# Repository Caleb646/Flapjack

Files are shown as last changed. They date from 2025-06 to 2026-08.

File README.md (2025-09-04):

# 🥞 Flapjack

Flapjack is a **VTOL drone platform** built from the ground up — custom **airframe**, **PCB**, and **firmware**.
---

## Features

- **Custom Flight Controller PCB**
    - STM32 microcontroller
    - IMU (SPI), barometer, GPS, and compass
    - Servo and ESC outputs

- **Firmware**
    - Python GUI for flight data
    - Real-time flight control loop
    - Sensor fusion (IMU + barometer + compass)
    - PID control
    - PID Mixing for tilt-thrust VTOL (motor + servo)

- **Airframe**
    - Dual-motor VTOL design with tilt servos
    - Lightweight and modular construction
    - Designed for hover-to-cruise transitions

---

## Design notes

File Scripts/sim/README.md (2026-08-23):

# Flapjack JSBSim HIL Simulator

Hardware-in-the-loop sim for the tilt-rotor. The firmware runs on the real
STM32H745 **or on an emulated CM7 under Renode** (see [SIL mode](#sil-mode-no-board-required)
below); this PC tool runs **JSBSim** and exchanges data with it over the (now
binary) debug UART:

```
 PC: JSBSim + bridge.py  ◄──ServoCmd/MotorCmd────  FC (sim driver profile)
                         ◄──Telemetry────────────  (validation + sensor loopback)

                         ──CRSF 0x16────────────►  FC RX UART  (USART3)
                         ──NMEA GGA/RMC─────────►  FC GPS UART (USART2)

                         ──accel, gyro──────────►  emulated BMI323  (tcp 4010) ─► SPI1
                         ──field────────────────►  emulated MMC5983 (tcp 4011) ─┐
                         ──Pa, degC─────────────►  emulated BMP390  (tcp 4012) ─┴► SPI5
```

**Nothing reaches the FC pre-decoded.** RC and GPS go down separate wires as real
CRSF and real NMEA, exactly as the parts would drive them, so a SIL run exercises
the UART ISRs, the deframing, the checksums and the parsers. There used to be an
`RcInput` sim-link message that wrote `g_Rx.channels` directly; it bypassed all
of that and has been removed.

The three **sensors** follow the same principle one level down. A register read
is not a byte protocol, but it is still a path with a chip select, a dummy byte,
an address auto-increment and a data-ready bit to get wrong — so rather than
inject decoded values at the driver, the bridge pushes physical quantities into
emulated parts and the firmware reads them back through its real `bmi323`,
`mmc5983` and `bmp390` drivers over emulated SPI. That put five firmware defects
on the record for the IMU alone (KnownIssues §2.29–§2.33), and for the baro it
puts the 21-byte calibration decode and the compensation polynomial on the
critical path.

**Frame ids 1 (`SensorData`), 2 (`RcInput`) and 7 (`BaroData`) are retired — do
not reuse them.** The sim link is FC→PC only now, apart from the shell.

- **PC → FC:** IMU (accel m/s², gyro deg/s) and mag (**gauss**) pushed at 400 Hz,
  baro (Pa, °C) at 50 Hz, each into its own emulated part; RC channels as CRSF
  `0x16` frames on the RX UART; GPS as NMEA `GGA`/`RMC` on the GPS UART.
- **FC → PC:** per-servo tilt **angle** (rad) and per-motor **throttle** (0–1),
  plus a `Telemetry` frame (nav euler, armed, IMU sample count, RC link state,
  and the baro/GPS **loopback** described below).

Mag is pushed in gauss, not as a unit vector, because the MMC5983 has a real
±8 G full scale that `mmc5983.c` divides by — a unit vector would assert that
Earth's field saturates the part. Nothing downstream depends on the magnitude
(Madgwick renormalises), but the scale is now a testable property rather than an
assumption.

### The sensor loopback

`Telemetry` echoes back the baro pressure and GPS fix the firmware decoded, read
from the **umsg topics** rather than from the sim link's own decode slots. The
bridge asserts every echo matches something it actually sent:

- **baro: bit-exact.** Both hops are IEEE 754 binary32, so a correct chain
  reproduces the sent value exactly — no tolerance, and under `--dry-run` the
  pressure is *swept* so a latched or stale value cannot pass by accident.
- **GPS: within ~1.1 cm.** NMEA quantises the coordinate to 5 decimal places of a
  minute (~1.9 cm), so the check compares against the post-quantisation value.
  The tolerance is tight enough that narrowing the chain back to `float`
  (~2.2e-6 deg at mid latitudes) fails.

This covers the whole chain — wire, driver, device, umsg publish — in one
comparison. It is specifically the check that catches a parser which succeeds
while discarding its result, which is exactly what `Gps_Update_` used to do.

Timing is **free-running real-time**: sensors stream at a fixed rate and JSBSim
is stepped to wall-clock; the FC consumes the latest sample and replies async.

## 1. Install

From the repo root (installs JSBSim + the shared base deps):

```
pip install -e ".[sim]"
```

The Python proto stub lives at `Scripts/proto/sim_pb2.py` and is regenerated
(alongside the firmware's nanopb `Firmware/msgs/proto/sim.pb.{c,h}`) by:

```
python Scripts/board.py gen
```

(`build -b flapjack-v1 -D sim -f g` regenerates the same as part of a full build.)
`sim.proto` is the **single source of truth** for both.

## 2. Build + flash the HIL firmware

Configure the firmware with the `sim` driver profile (selects the sim backends
for imu/mag/baro/servo/motor and defines `SIM_HIL`):

```
python Scripts/board.py build -b flapjack-v1 -D sim
```

In this build the shared UART (UART_1, `SERIAL_LINK_BAUD_RATE` = 460800) carries binary sim
frames **and** ASCII debug logs, interleaved; the shell shares it too, as frame id
6. `bridge.py` separates them and prints the log text to stdout. Log output is
7-bit ASCII and the frame magic is `0xAA`, which is what makes the two
unambiguous — see `Firmware/drivers/serial/serial_link.h`.

Wire the board's UART_1 TX/RX to a USB-serial adapter on the PC. On real hardware
the receiver drives UART_3 (`RX_UART`, 416666 baud 8N1) as usual — the bridge's
`--rc-port` stands in for it only under Renode.

## 3. Bring up the link FIRST (no FDM needed)

`--dry-run` skips JSBSim and emits a fixed **20° roll** attitude. This validates
the serial link, the FC's sensor decode/frames, and the telemetry echo without
any flight model:

```
python Scripts/board.py sim --port COM7 --dry-run
```

Expected: the `[FC] euler(deg)=` line should converge to roll ≈ **+20°**,
`armed=True` shortly after start, and `imu#` increasing (proves the IMU task is
paced by the incoming stream). If euler roll is negative or on the wrong axis,
flip the sign in `synthesize_sensors()` (clearly marked).

## 4. Run the full sim

```
python Scripts/board.py sim --port COM7
```

The bridge loads `Scripts/sim/jsbsim/aircraft/tiltrotor/tiltrotor.xml`, raises the
arm switch after `--arm-delay`, waits for the FC to report armed, then goes to
hover throttle, applies the FC's servo/motor commands to the model, and streams
synthesized sensors back.

**Every wire defaults to its SIL socket**, so a SIL run is just `board.py sim` with no flags.
The defaults apply only while `--port` is a socket, i.e. while this is a SIL run — naming a real
device turns them all off, because on a board the companion wires are physical ports nobody can
guess. Pass `none` to any one of them (`--gps-port none`) to leave that wire off, which is how
the "no receiver" and "no fix" paths stay testable. Useful flags:

| flag | default | meaning |
|---|---|---|
| `--port` | `socket://localhost:4000` | the FC's sim link. The default is a SIL run; give a real device (`COM7`, `/dev/ttyUSB0`) to drive a board |
| `--baud` | 460800 | must match the board's `SERIAL_LINK_BAUD_RATE` |
| `--rate` | 400 | sensor stream rate (Hz) |
| `--model` | tiltrotor | JSBSim aircraft name under `--root/aircraft/` |
| `--hover-throttle` | 0.5 | throttle held once armed, when no `--plan` is given |
| `--rc-port` | `socket://localhost:4001` | port carrying CRSF to the FC's RX UART. **The only RC path** — with `none` the FC never arms |
| `--rc-baud` | 416666 | CRSF spec default; ignored for a `socket://` URL |
| `--rc-rate` | 50 | CRSF frame rate (Hz); a real link runs 50–150 |
| `--imu-port` | `socket://localhost:4010` | socket carrying accel/gyro to the emulated BMI323. **The only IMU path** — with `none` there is no attitude |
| `--mag-port` | `socket://localhost:4011` | socket carrying the field in gauss to the emulated MMC5983. **The only mag path** |
| `--mag-rate` | 100 | magnetometer push rate (Hz). The emulated part raises drdy on every push, so this **is** the FC's mag interrupt rate — it matches the 100 Hz `mmc5983.c` programs, and pushing faster models a part the board does not have |
| `--baro-port` | `socket://localhost:4012` | socket carrying Pa/°C to the emulated BMP390. **The only baro path** |
| `--baro-rate` | 50 | barometer push rate (Hz), matching the ODR `bmp390.c` programs; also the FC's baro interrupt rate. 0 disables baro |
| `--gps-port` | `socket://localhost:4002` | port carrying NMEA to the FC's GPS UART. **The only GPS path** |
| `--gps-baud` | 115200 | matches `GPS_BAUD_RATE`; ignored for a `socket://` URL |
| `--gps-rate` | 10 | fix rate (Hz). GGA and RMC go out half a period apart — the driver holds one sentence, so a burst would lose the first |
| `--plan` | (none) | YAML flight plan to fly once armed |
| `--rc-stop` | (none) | stop sending CRSF after N seconds, imitating a receiver failsafe |
| `--hold-until-armed` | on | freeze the FDM at its IC until the FC arms |

### Flight plans

`--plan Scripts/sim/plans/hover.yaml` replays a scripted stick sequence instead
of the fixed arm-and-hover gesture. A plan is a list of timed segments that `set`
or `ramp` named channels in microseconds:

```yaml
name: yaw_step
plan:
  - {t: 0.0,  dur: 3.0}
  - {t: 3.0,  dur: 2.0, ramp: {throttle: 1500}}
  - {t: 8.0,  dur: 2.0, set:  {yaw: 1700}}
  - {t: 10.0, dur: 3.0, set:  {yaw: 1500}}
```

Two properties make runs comparable. **Arming is a barrier, not a timestamp** —
the plan clock starts when the FC reports armed, because the attitude-settle gate
takes a variable amount of time (measured anywhere from 3 s to ~24 s). And **`t`
is simulation time**: the FDM advances exactly one `dt` per tick, so `tick * dt`
is exact, where wall-clock pacing would move the sticks around under host load.

When the plan ends the bridge prints a check summary and exits **0 (pass) or
1 (fail)**. The checks are physics invariants — no NaN, motors inside [0,1] and
not pinned at 1.000, servos inside ±π/2, FC actually armed — which hold of any
correct flight whatever the plan. Per-plan criteria live in the plan itself; see
**Phase-gated plans** below.

> §1.13 records that the attitude a run settles at is not repeatable and is a
> weak regression signal. That was a property of the **rate** loop it was
> measured on: centred sticks commanded zero rate, so the vehicle kept whatever
> bank the transient left. `guidance.c` holds an **angle** now — centred means
> level — so there is a commanded reference to track, which is what phase gates
> compare against.

The **sensor loopback** lines are the exception: they *are* exact assertions, and
they can be, because they compare the firmware against what the bridge itself
sent rather than against an unvalidated flight model. A healthy run reads:

```
[checks] baro         2342 sent, 2331 echoed, 0 mismatched
[checks] gps          976 sent, 976 echoed, 0 mismatched
```

Both lines are silent when the sensor was not streamed, so an older plan or a
`--baro-rate 0` run still passes. `0 echoed` against a non-zero `sent` is a
failure, not a skip — that is the "FC decoded none" case.

### Phase-gated plans

A plain `plan:` is stick input: it flies, but the only thing asserted afterwards
is that the vehicle did not depart or go NaN. A **`phases:`** plan carries its
own PASS/FAIL criteria, and is what `acceptance.yaml` — the regression run — is
built from:

```yaml
name: acceptance
phases:
  - name: climb_in_roll_right
    set:    {roll: 1700, throttle: 1800}   # +12 deg of bank, +0.6 m/s climb
    settle: 4.0                            # transient — NOT gated
    hold:   12.0                           # gates checked on EVERY tick here
    gates:
      roll_deg:     {target: cmd, tol: 2.0}
      climb_mps:    {target: cmd, tol: 0.20}
      pitch_deg:    {target: 0.0, tol: 3.0}   # uncommanded → coupling gate
      yaw_rate_dps: {target: 0.0, tol: 8.0}
```

`set`/`ramp` are applied over `settle`, then the sticks are held still for
`hold`. Splitting them is the point: *did it get there* and *did it stay there*
are different questions, and only the second is a stability check.

**Gate targets.** `target: cmd` compares against what the sticks were asking
for, derived from the plan by `plan.commanded()` — roll and pitch are **angle**
commands (`(µs-1500)/500 × CFG_ANGLE_MAX_DEG`), yaw is a **rate**, throttle is a
**climb rate**. `target: <number>` compares against a constant, which is how an
axis nobody commanded gets asserted — and that is the cross-coupling check: a
roll input that drags pitch with it fails `pitch_deg` even while tracking roll
perfectly.

| gate | measured | kind |
|---|---|---|
| `roll_deg`, `pitch_deg` | FDM truth euler | per-sample |
| `yaw_rate_dps` | FDM truth body rate | per-sample |
| `climb_mps` | FDM `h-dot` | per-sample |
| `alt_drift_m` | altitude change across the hold | per-phase |
| `heading_drift_dps` | heading change ÷ hold length | per-phase |

The drift gates are the reason a long phase is worth flying: `acceptance.yaml`'s
`long_trim_hold` is 150 s of centred sticks, and nothing a 20 s plan does can
express what it asserts.

**The reference comes from the plan, not from the FC.** Comparing the firmware's
own setpoint echo against its own estimate would pass a vehicle that is
confidently wrong — the same argument `KnownIssues.md` §1.16 makes for gating on
FDM truth rather than on `Telemetry.euler`.

**Failures are loud and early.** The first violation prints the instant it
happens with its phase, plan time, expected and measured values, and the run
**stops** — so the failure is the last thing on the terminal instead of buried
under the remaining minutes of log. `--keep-going` surveys the rest instead.
Everything gate-related is prefixed `[gate]`, so `grep '^\[gate\]'` is the whole
report; logs, telemetry and the shell all share USART1, which is what makes that
matter. A machine-readable copy lands in `Build/sil_report.json`
(`--gate-report`), for diffing one build against another.

```
[gate] ------------------------------------------------------------
[gate] phase                 gate               worst   limit      n
[gate] climb_in_roll_right   roll_deg           0.812   2.000    4800  PASS
[gate] climb_in_roll_right   pitch_deg          3.441   3.000    4800  FAIL
[gate] not reached: level_1, climb_in_roll_left, ...
[gate] FIRST FAILURE  climb_in_roll_right/pitch_deg at plan t=63.20s
[gate]   expected +0.000, measured -3.441, error 3.441 > tol 3.000
[gate] FAIL (1 failed, 22 never ran)
```

**A gate that never ran fails.** A phase shorter than a tick, or one the run
aborted before reaching, reports `NOT RUN` and counts against the verdict — a
green line for a criterion nobody evaluated is exactly how a regression suite
stops meaning anything. Gate and channel names are validated at load, so a typo
is an error rather than a gate that silently never fires.

**Tolerances must be measured, not guessed.** `acceptance.yaml`'s are starting
values and are marked as such. Fly it several times on a known-good build, take
the worst error each gate actually reaches, set the limit near 3× that, and
record the spread in a comment — the treatment `ATTITUDE_SETTLE_PKPK_DEG` in
`bridge.py` already documents. A flaky gate is worse than no gate.

## Wire protocol

`[0xAA][0x55][msg_id][len][payload][crc8]` — `crc8` poly 0x07, init 0x00, over
`(msg_id,len,payload)`; payload is protobuf (`sim.proto`). Defined identically in
`Firmware/drivers/sim_link/sim_link.c` and the shared host framing
`Scripts/link/framing.py` (used by the bridge).

## Status / caveats

- **The CRSF path is unit-tested on the host.** `Tests/UnitTest/test_crsf.c` checks
  the firmware's deframer, CRC, channel unpack and tick→µs mapping against the spec,
  and asserts a golden frame produced by `Scripts/sim/crsf.py` byte for byte, so the
  encoder here and the decoder there cannot drift apart.
- **The NMEA path is too.** `Tests/UnitTest/test_gps.c` does the same job for GPS
  against golden sentences from `Scripts/sim/nmea.py`: the byte assembler
  (resync, partial sentences, one-byte-at-a-time delivery), the coordinate and
  knots→m/s conversions, checksum rejection, and that a void RMC or a
  `fix_quality` 0 GGA is **not** reported as a fix.
- **The sensor models come from JSBSim.** `SensorBaro.xml` and `SensorGps.xml` are
  vendored into `jsbsim/systems/` from the JSBSim distribution and included by
  `tiltrotor.xml`. Their `<noise>`/`<bias>`/`<drift_rate>` terms are **on** — see
  `KnownIssues.md` §3.13 for each value and why. Tune realism **there**, not in
  `bridge.py`. There is still **no IMU noise model**: the gyro and accel the
  bridge synthesises are exact. `SensorImu.xml` is deliberately **not** used —
  its accelerometer reports the opposite Z sign to this project's convention, and
  its magnetometer disagrees with WMM in both sign and magnitude (32.2 µT against
  ~48 µT real).
- **The FDM is sized to the real airframe** (0.85 kg, 7 in props, 1000 KV assumed
  on 6S): hover at 50 % throttle, 2:1 thrust-to-weight, tilt verified against
  measured force directions. Thrust comes from `<external_reactions>` rather than
  JSBSim's propeller model, which diverged — see `SilResearch.md` §6.
  Inertias are still estimates, and `ROTOR_TMAX` (1.874 lbf per rotor) is the one
  number to replace with thrust-stand data.
- **Forward flight is approximated** by a thrust-vs-airspeed table rather than
  blade-element physics. Fine for hover and low-speed control work; revisit before
  trusting cruise or transition results.
- **The gains are provisional.** The stack flies closed-loop, but the tune is
  fitted to an estimated rotor height and unmeasured servo dynamics — see
  `KnownIssues.md` §1.9. `roll_pitch.yaml` still departs (§1.14); `hover`,
  `yaw_step` and `alt_hold` pass.

---

## SIL mode (no board required)

Renode emulates the CM7 and exposes **both** UARTs as TCP servers, so the bridge
talks to sockets instead of COM ports — USART1 (sim link) on 4000 and USART3
(the RX UART, carrying CRSF) on 4001. Nothing else changes: same framing, same
protobuf messages, same `bridge.py`.

```bash
python Scripts/board.py build -b flapjack-v1 -D sim --single-core
python Scripts/board.py renode -b flapjack-v1                          # terminal 1
python Scripts/board.py sim                                            # terminal 2
```

USART2 (the GPS UART) is exposed on **4002** alongside the other two. Like
USART3 it needed no Renode work beyond a frequency pin — it is a real
`UART.STM32F7_USART` in the shipped platform. `--gps-port` is optional: leave it
off and `Gps_Task` simply never sees a fix, and the GPS checks stay silent.

`renode` takes the place of `flash`; it blocks until Ctrl-C. **Restart it between
runs** rather than re-attaching the bridge: a gap in the sensor stream hands
`Nav_Update` one enormous `dt`, which throws the attitude estimate and costs
several seconds of recovery.

Measured behaviour (see `SilResearch.md` §3):

- Renode tracks wall clock **1.00x** under load, so the bridge's real-time pacing
  is correct as-is.
- **400 Hz sustains with 0.0 % dropped `SensorData`**; the ceiling is ~740/s,
  beyond which throughput collapses.
- `Telemetry.imu_count` vs frames sent is the health metric — it should track 1:1.

The FC arms itself: `bridge.py` holds throttle low with the switch up after
`--arm-delay` (2.0 s) and waits for `Telemetry.armed`. The interlock that decides
when is in the firmware, not the bridge — the estimate must be converged and
still for 3 s (`KnownIssues.md` §2.13) — so arming lands anywhere from ~3 s to
~24 s in. Ground start and landing are fine; the gear no longer diverges (§3.4).

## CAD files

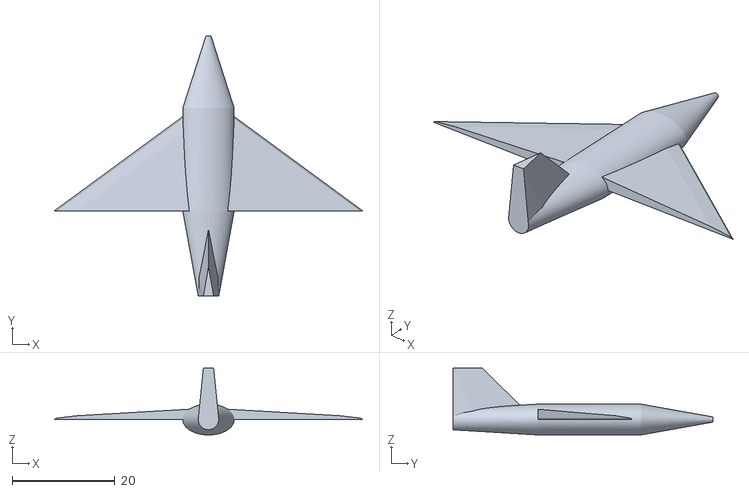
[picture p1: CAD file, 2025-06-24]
Scripts/gui/data/mesh/plane.stl
60.0 x 50.5 x 13.0

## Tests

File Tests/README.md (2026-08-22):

# Flapjack tests

Two independent suites that share nothing but the vendored Unity in `Tests/unity/`.

| | `Tests/UnitTest/` | `Tests/HIL/` |
|---|---|---|
| Runs on | the host (x86) | the board |
| Built by | `Tests/CMakeLists.txt` (standalone CMake project) | the firmware build, `board.py build -f t` |
| Purpose | pure logic against controlled inputs | drivers against real peripherals |

---

## Host unit tests

```bash
cmake -S Tests -B Build/UnitTest -G "MinGW Makefiles"   # "Unix Makefiles" on Linux
cmake --build Build/UnitTest
ctest --test-dir Build/UnitTest --output-on-failure
```

No toolchain and no network needed — this compiles firmware sources with the host compiler
against `UnitTest/stubs/hal_stub.c`, and Unity is vendored rather than fetched.

### Current contents

Four suites. Two of them assert a **golden frame** produced by the host encoder the SIL uses, so
the encoder there and the decoder here cannot drift apart.

- **`test_crsf.c`** — the receiver path in `drivers/rx/crsf.c` against the TBS CRSF specification:
  frame layout and the 2–62 length range, CRC8 (poly 0xD5, over type + payload), the
  16 × 11-bit LSB-first channel unpack, the `TICKS_TO_US` mapping, and the spec's rule that a
  longer-than-expected frame must be accepted with its extra fields ignored. Golden frame from
  `Scripts/sim/crsf.py`.
- **`test_gps.c`** — the NMEA path: the byte assembler (resync, partial sentences,
  one-byte-at-a-time delivery), the coordinate and knots→m/s conversions, checksum rejection, and
  that a void RMC or a `fix_quality` 0 GGA is **not** reported as a fix. Golden sentences from
  `Scripts/sim/nmea.py`.
- **`test_altitude.c`** — the ISA pressure conversion against an **analytic oracle** (SilResearch
  §5.2), plus the vertical complementary filter: convergence to the measurement, acceleration
  integration in between, and bias absorption.
- **`test_align.c`** — the board/sensor alignment composition.

### Adding a test

Add the source under `UnitTest/`, then in `Tests/CMakeLists.txt` put its firmware dependencies in
an `add_library(... OBJECT ...)` and register it:

```cmake
add_test_exe(test_thing OBJECTS drone_common_obj drone_thing_obj)
```

Two constraints worth knowing before you pick what to compile in:

- **`spi.c` and `uart.c` do not build against the stub.** `stubs/hal_stub.c` has no `LL_SPI_*` and
  none of the `__HAL_UART_*` macros. Either extend the stub, or do what `test_crsf.c` does and
  define the two or three functions your unit actually needs directly in the test file.
- **MinGW needs `-mno-ms-bitfields`** (the build sets it globally). Under MSVC bitfield layout
  `CrsfChannelsPayload_t` packs to 32 bytes instead of the 22 ARM EABI produces, and the host would
  silently exercise a wire format the firmware never emits. `test_crsf.c` carries a
  `_Static_assert` on that size; do the same for any other struct whose memory layout is the thing
  under test.

Note that `GetMicroseconds()` returns **0** under `UNIT_TEST` (`core/core_shared.c`), so anything
gated on elapsed time — the CRSF inter-frame timeout, the RC link timeout — cannot be reached from
here. Those need a time seam that does not exist yet.

### History

This suite previously held tests for queue, vector, umap, gpio, spi, uart, imu, mag, dshot and
filter. None of them had built for some time: they all include `"unity/unity.h"`, while
`CMakeLists.txt` fetched Unity to `_deps/unity-src/src/`, where that path cannot resolve — and
several of their dependencies no longer compile against the HAL stub. They were removed rather
than left as decoration. Restoring any of them means fixing the target against the two constraints
above; the sources are in git history.

---

## HIL tests

Firmware compiled with `HIL_TEST=True` runs Unity on the board at boot and streams results over
UART:

```bash
python Scripts/board.py build -b flapjack-v1 -f t
python Scripts/board.py flash -b flapjack-v1 -f t --port <PORT> --baud 230400
```

`flash -f t` parses the stream and exits 0 (all pass) or 1 (failures). Output format:

```
file.c:42:test_name:PASS
file.c:43:test_name:FAIL:Expected X Was Y
N Tests M Failures 0 Ignored
```

---

## The third kind: the SIL

Neither suite covers the GNC loop end to end. That is the SIL's job — Renode plus JSBSim, driven
by `board.py renode` and `board.py sim`. A flight plan run (`sim --plan …`) exits 0 or 1 on a set
of physics invariants, which makes it usable as a coarse regression gate. See `SilResearch.md`
and the `flapjack-sil-debugging` skill.

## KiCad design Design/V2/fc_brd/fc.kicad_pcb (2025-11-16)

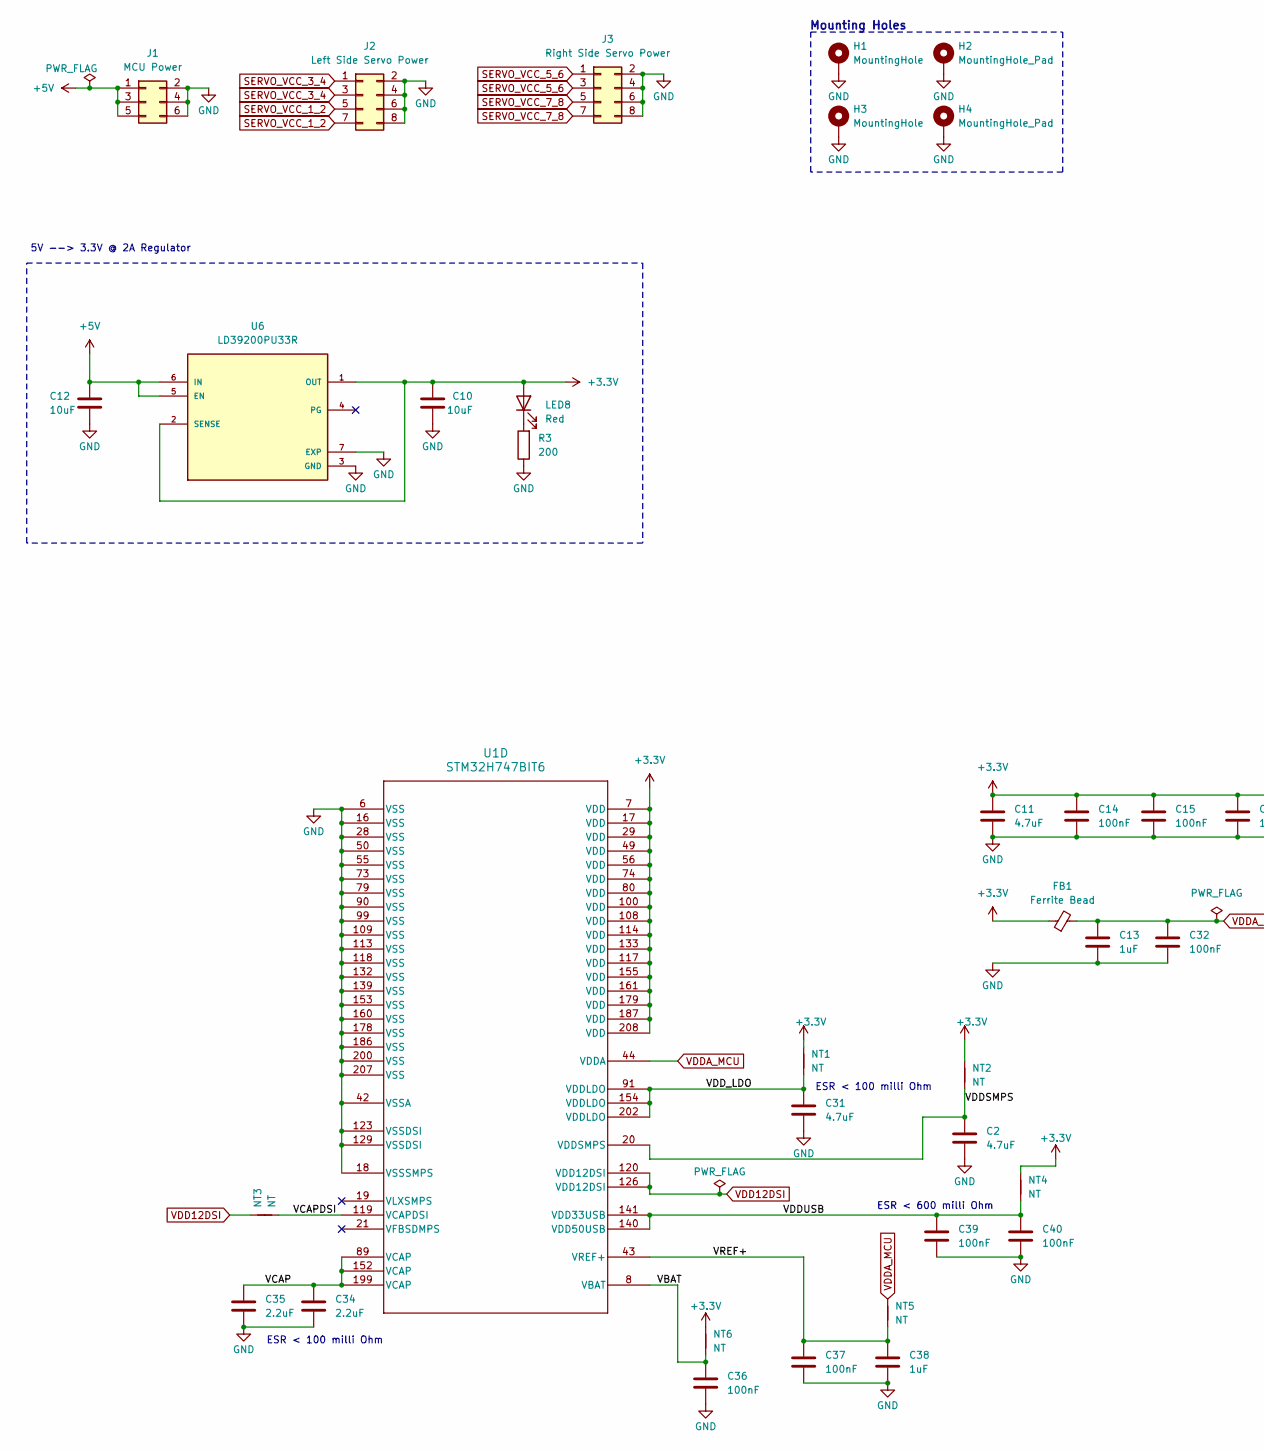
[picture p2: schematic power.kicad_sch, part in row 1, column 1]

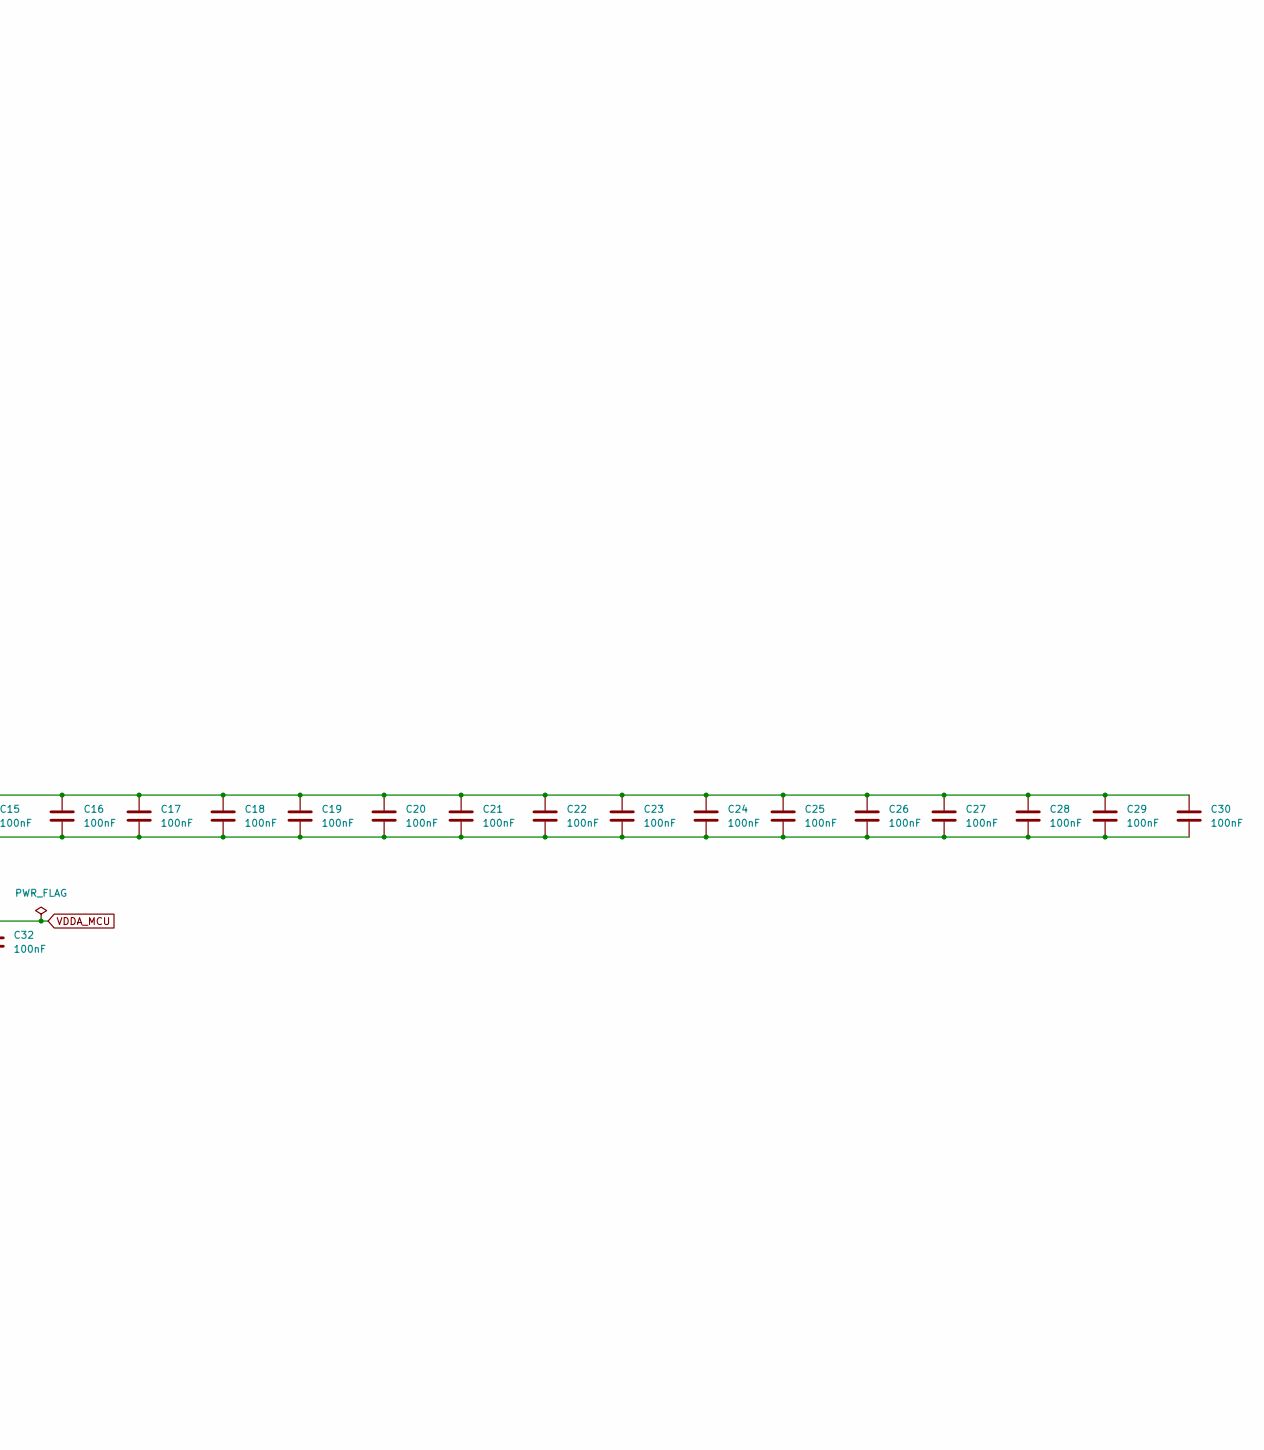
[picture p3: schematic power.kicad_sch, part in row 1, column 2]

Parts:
C2, C11, C31: 4.7uF; C_0603_1608Metric_Pad1.08x0.95mm_HandSolder; Manufacturer_Part_Number CL10A475KO8NNNC; LCSC Part # C19666
C10, C12: 10uF; C_0603_1608Metric_Pad1.08x0.95mm_HandSolder; Manufacturer_Part_Number CL10A106KP8NNNC; LCSC Part # C19702
C13, C38: 1uF; C_0603_1608Metric_Pad1.08x0.95mm_HandSolder; Manufacturer_Part_Number CL10A105KB8NNNC; LCSC Part # C15849
C14, C15, C16, C17, C18, C19, C20, C21, C22, C23, C24, C25, C26, C27, C28, C29, C30, C32, C36, C37, C39, C40: 100nF; C_0603_1608Metric_Pad1.08x0.95mm_HandSolder; Manufacturer_Part_Number CC0603KRX7R7BB104; LCSC Part # C14663
C34, C35: 2.2uF; C_0603_1608Metric_Pad1.08x0.95mm_HandSolder; Manufacturer_Part_Number CL10A225KO8NNNC; LCSC Part # C23630
FB1: Ferrite Bead; L_0603_1608Metric_Pad1.05x0.95mm_HandSolder; Manufacturer_Part_Number BLM18PG121SN1D; LCSC Part # C14709
H1, H3: MountingHole; MountingHole_3.2mm_M3_Pad_Via
H2, H4: MountingHole_Pad; MountingHole_3.2mm_M3_Pad_Via
J1: MCU Power; PinHeader_2x03_P2.54mm_Vertical
J2: Left Side Servo Power; PinHeader_2x04_P2.54mm_Vertical
J3: Right Side Servo Power; PinHeader_2x04_P2.54mm_Vertical
LED8: Red; LED_0603_1608Metric; Manufacturer_Part_Number KT-0603R; LCSC Part # C2286
NT1, NT2, NT3, NT4, NT5, NT6: NT; NetTie-2_SMD_Track0.35mm
R3: 200; R_0603_1608Metric_Pad0.98x0.95mm_HandSolder; Manufacturer_Part_Number 0603WAF2000T5E; LCSC Part # C8218
U1: STM32H747BIT6; STM32H747BIT6-LQFP-208; Manufacturer_Part_Number STM32H747BIT6; LCSC Part # C730197
U6: LD39200PU33R; SON95P300X300X100-7N; Manufacturer_Part_Number LD39200PU33R; LCSC Part # C222192

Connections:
/Power/VBAT: C36.1, NT6.2, U1.8 (VBAT)
/Power/VCAP: C34.1, C35.1, U1.89 (VCAP), U1.152 (VCAP), U1.199 (VCAP)
/Power/VCAPDSI: NT3.2, U1.119 (VCAPDSI)
/Power/VDDSMPS: C2.1, NT2.2, U1.20 (VDDSMPS)
/Power/VDDUSB: C39.1, C40.1, NT4.2, U1.140 (VDD50USB), U1.141 (VDD33USB)
/Power/VDD_LDO: C31.1, NT1.2, U1.91 (VDDLDO), U1.154 (VDDLDO), U1.202 (VDDLDO)
/Power/VREF+: C37.1, C38.1, NT5.2, U1.43 (VREF+)
GND: C2.2, C10.2, C11.2, C12.2, C13.2, C14.2, C15.2, C16.2, C17.2, C18.2, C19.2, C20.2, C21.2, C22.2, C23.2, C24.2, C25.2, C26.2, C27.2, C28.2, C29.2, C30.2, C31.2, C32.2, C34.2, C35.2, C36.2, C37.2, C38.2, C39.2, C40.2, H1.1, H2.1, H3.1, H4.1, J1.2, J1.4, J1.6, J2.2, J2.4, J2.6, J2.8, J3.2, J3.4, J3.6, J3.8, R3.1, U1.6 (VSS), U1.16 (VSS), U1.18 (VSSSMPS), U1.28 (VSS), U1.42 (VSSA), U1.50 (VSS), U1.55 (VSS), U1.73 (VSS), U1.79 (VSS), U1.90 (VSS), U1.99 (VSS), U1.109 (VSS), U1.113 (VSS), U1.118 (VSS), U1.123 (VSSDSI), U1.129 (VSSDSI), U1.132 (VSS), U1.139 (VSS), U1.153 (VSS), U1.160 (VSS), U1.178 (VSS), U1.186 (VSS), U1.200 (VSS), U1.207 (VSS), U6.3 (GND), U6.7 (EXP); also elsewhere on the board
unnamed: LED8.1 (K), R3.2
SERVO_VCC_1_2: J2.5, J2.7; also elsewhere on the board
SERVO_VCC_3_4: J2.1, J2.3; also elsewhere on the board
SERVO_VCC_5_6: J3.1, J3.3; also elsewhere on the board
SERVO_VCC_7_8: J3.5, J3.7; also elsewhere on the board
VDD12DSI: NT3.1, U1.120 (VDD12DSI), U1.126 (VDD12DSI)
VDDA_MCU: C13.1, C32.1, FB1.2, NT5.1, U1.44 (VDDA)

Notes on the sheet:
5V --> 3.3V @ 2A Regulator
Mounting Holes
ESR < 100 milli Ohm
ESR < 600 milli Ohm

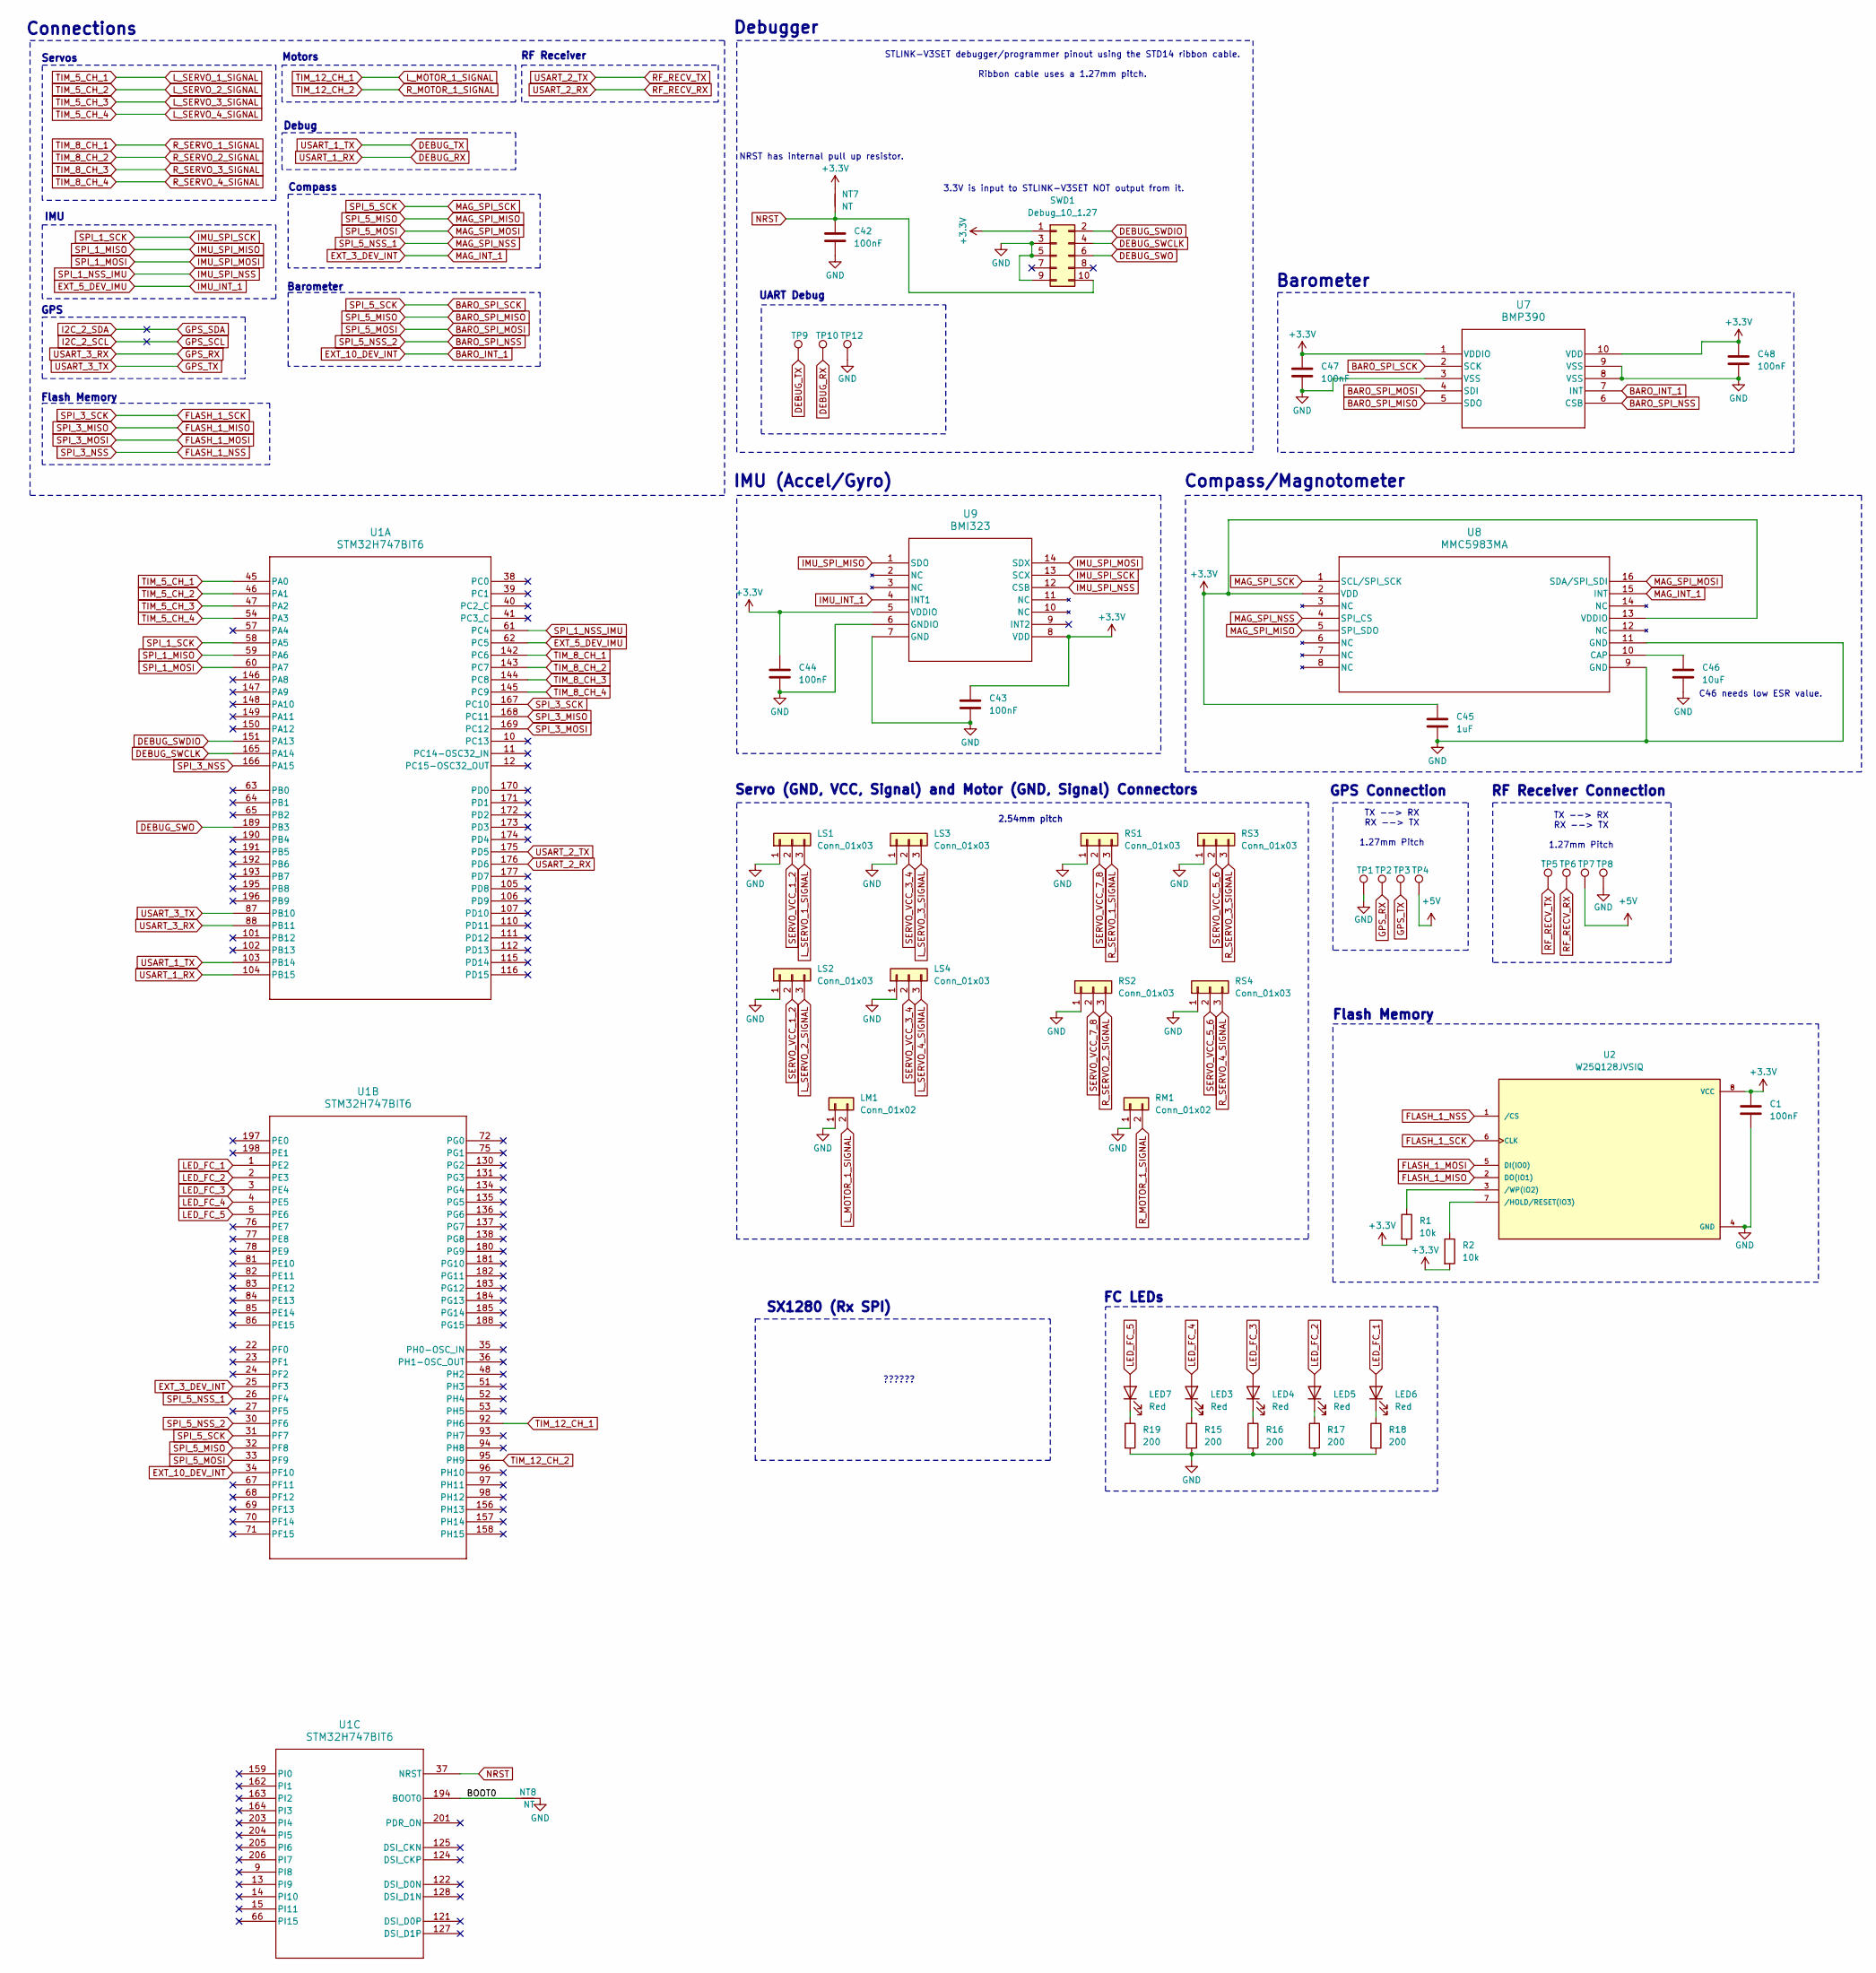
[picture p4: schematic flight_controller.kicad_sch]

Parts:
C1, C42, C43, C44, C47, C48: 100nF; C_0603_1608Metric_Pad1.08x0.95mm_HandSolder; Manufacturer_Part_Number CC0603KRX7R7BB104; LCSC Part # C14663
C45: 1uF; C_0603_1608Metric_Pad1.08x0.95mm_HandSolder; Manufacturer_Part_Number CL10A105KB8NNNC; LCSC Part # C15849
C46: 10uF; C_0805_2012Metric_Pad1.18x1.45mm_HandSolder; Manufacturer_Part_Number CL21A106KAYNNNE; LCSC Part # C15850
LED3, LED4, LED5, LED6, LED7: Red; LED_0603_1608Metric; Manufacturer_Part_Number KT-0603R; LCSC Part # C2286
LM1: Conn_01x02; PinHeader_2x01_P2.54mm_Vertical
LS1, LS2, LS3, LS4: Conn_01x03; PinHeader_1x03_P2.54mm_Vertical
NT7, NT8: NT; NetTie-2_SMD_Track0.35mm
R1, R2: 10k; R_0603_1608Metric_Pad0.98x0.95mm_HandSolder; Manufacturer_Part_Number 0603WAF1002T5E; LCSC Part # C25804
R15, R16, R17, R18, R19: 200; R_0603_1608Metric_Pad0.98x0.95mm_HandSolder; Manufacturer_Part_Number 0603WAF2000T5E; LCSC Part # C8218
RM1: Conn_01x02; PinHeader_2x01_P2.54mm_Vertical
RS1, RS2, RS3, RS4: Conn_01x03; PinHeader_1x03_P2.54mm_Vertical
SWD1: Debug_10_1.27; CONN_GRPB052VWQS-RC_OddEven_2x5Pins_1.27mm; Manufacturer_Part_Number GRPB052VWQS-RC
TP1, TP2, TP3, TP4, TP5, TP6, TP7, TP8, TP9, TP10, TP12: TestPoint; TestPoint_Pad_1.0x1.0mm
U1: STM32H747BIT6; STM32H747BIT6-LQFP-208; Manufacturer_Part_Number STM32H747BIT6; LCSC Part # C730197
U2: W25Q128JVSIQ; SOIC127P790X216-8N; PARTREV I; LCSC Part # C97521
U7: BMP390; BMP390-10LGA_2X2X0p75_BOS; Manufacturer_Part_Number BMP390; LCSC Part # C5124834
U8: MMC5983MA; MMC5983MA_MEM; Manufacturer_Part_Number MMC5983MA; LCSC Part # C404329
U9: BMI323; BMI323_BOS; Manufacturer_Part_Number BMI323; LCSC Part # C5368700

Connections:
/Flight Controller/BOOT0: NT8.1, U1.194 (BOOT0)
BARO_INT_1: U1.34 (PF10), U7.7 (INT)
BARO_SPI_MISO: U1.32 (PF8), U7.5 (SDO), U8.5 (SPI_SDO)
BARO_SPI_MOSI: U1.33 (PF9), U7.4 (SDI), U8.16 (SDA/SPI_SDI)
BARO_SPI_NSS: U1.30 (PF6), U7.6 (CSB)
BARO_SPI_SCK: U1.31 (PF7), U7.2 (SCK), U8.1 (SCL/SPI_SCK)
DEBUG_RX: TP10.1, U1.104 (PB15)
DEBUG_SWCLK: SWD1.4, U1.165 (PA14)
DEBUG_SWDIO: SWD1.2, U1.151 (PA13)
DEBUG_SWO: SWD1.6, U1.189 (PB3)
DEBUG_TX: TP9.1, U1.103 (PB14)
EXT_3_DEV_INT: U1.25 (PF3), U8.15 (INT)
EXT_5_DEV_IMU: U1.62 (PC5), U9.4 (INT1)
FLASH_1_MISO: U1.168 (PC11), U2.2 (DO(IO1))
FLASH_1_MOSI: U1.169 (PC12), U2.5 (DI(IO0))
FLASH_1_NSS: U1.166 (PA15), U2.1 (/CS)
FLASH_1_SCK: U1.167 (PC10), U2.6 (CLK)
GND: C1.2, C42.2, C43.2, C44.2, C45.2, C46.2, C47.2, C48.2, LM1.1, LS1.1, LS2.1, LS3.1, LS4.1, NT8.2, R15.2, R16.2, R17.2, R18.2, R19.2, RM1.1, RS1.1, RS2.1, RS3.1, RS4.1, SWD1.3, SWD1.5, SWD1.9, TP1.1, TP8.1, TP12.1, U2.4 (GND), U7.3 (VSS), U7.8 (VSS), U7.9 (VSS), U8.9 (GND), U8.11 (GND), U9.6 (GNDIO), U9.7 (GND); also elsewhere on the board
GPS_RX: TP2.1, U1.88 (PB11)
GPS_TX: TP3.1, U1.87 (PB10)
IMU_SPI_MISO: U1.59 (PA6), U9.1 (SDO)
IMU_SPI_MOSI: U1.60 (PA7), U9.14 (SDX)
IMU_SPI_NSS: U1.61 (PC4), U9.12 (CSB)
IMU_SPI_SCK: U1.58 (PA5), U9.13 (SCX)
LED_FC_1: LED6.2 (A), U1.1 (PE2)
LED_FC_2: LED5.2 (A), U1.2 (PE3)
LED_FC_3: LED4.2 (A), U1.3 (PE4)
LED_FC_4: LED3.2 (A), U1.4 (PE5)
LED_FC_5: LED7.2 (A), U1.5 (PE6)
L_MOTOR_1_SIGNAL: LM1.2, U1.92 (PH6)
L_SERVO_1_SIGNAL: LS1.3, U1.45 (PA0)
L_SERVO_2_SIGNAL: LS2.3, U1.46 (PA1)
L_SERVO_3_SIGNAL: LS3.3, U1.47 (PA2)
L_SERVO_4_SIGNAL: LS4.3, U1.54 (PA3)
MAG_SPI_NSS: U1.26 (PF4), U8.4 (SPI_CS)
NRST: C42.1, NT7.2, SWD1.10, U1.37 (NRST)
unnamed: LED3.1 (K), R15.1
unnamed: LED4.1 (K), R16.1
unnamed: LED5.1 (K), R17.1
unnamed: LED6.1 (K), R18.1
unnamed: LED7.1 (K), R19.1
unnamed: R2.1, U2.7 (/HOLD/RESET(IO3))
unnamed: R1.1, U2.3 (/WP(IO2))
unnamed: C46.1, U8.10 (CAP)
RF_RECV_RX: TP6.1, U1.176 (PD6)
RF_RECV_TX: TP5.1, U1.175 (PD5)
R_MOTOR_1_SIGNAL: RM1.2, U1.95 (PH9)
R_SERVO_1_SIGNAL: RS1.3, U1.142 (PC6)
R_SERVO_2_SIGNAL: RS2.3, U1.143 (PC7)
R_SERVO_3_SIGNAL: RS3.3, U1.144 (PC8)
R_SERVO_4_SIGNAL: RS4.3, U1.145 (PC9)
SERVO_VCC_1_2: LS1.2, LS2.2; also elsewhere on the board
SERVO_VCC_3_4: LS3.2, LS4.2; also elsewhere on the board
SERVO_VCC_5_6: RS3.2, RS4.2; also elsewhere on the board
SERVO_VCC_7_8: RS1.2, RS2.2; also elsewhere on the board

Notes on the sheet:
RF Receiver
TX --> RX RX --> TX 1.27mm Pitch
Connections
2.54mm pitch
UART Debug
3.3V is input to STLINK-V3SET NOT output from it.
GPS Connection
RF Receiver Connection
GPS
NRST has internal pull up resistor.
Compass
SX1280 (Rx SPI)
Debugger
Flash Memory
IMU (Accel/Gyro)
C46 needs low ESR value.
Motors
Servos
IMU
Compass/Magnotometer
??????
Servo (GND, VCC, Signal) and Motor (GND, Signal) Connectors
Barometer
STLINK-V3SET debugger/programmer pinout using the STD14 ribbon cable. Ribbon cable uses a 1.27mm pitch.
Debug
FC LEDs
Flash Memory

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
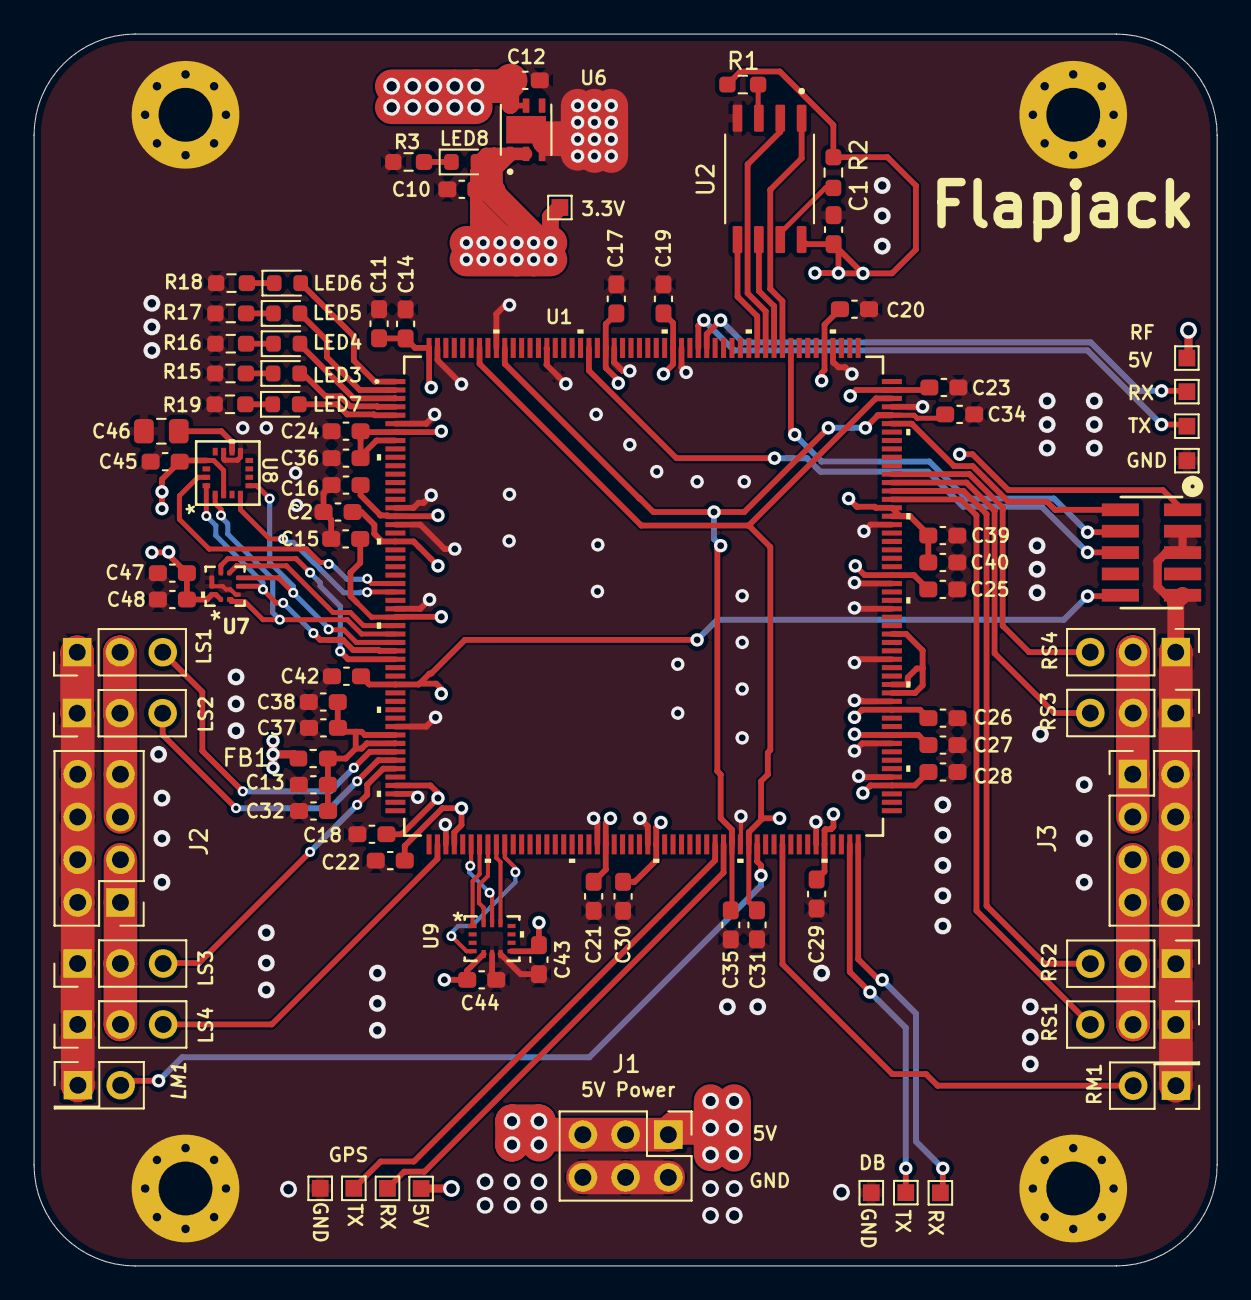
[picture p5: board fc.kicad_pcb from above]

Board: 4 copper layers, 70.3 x 73.2 mm, 98 parts (0 on the bottom side), 67 nets.

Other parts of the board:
TP7#2: TestPoint; TestPoint_Pad_1.0x1.0mm

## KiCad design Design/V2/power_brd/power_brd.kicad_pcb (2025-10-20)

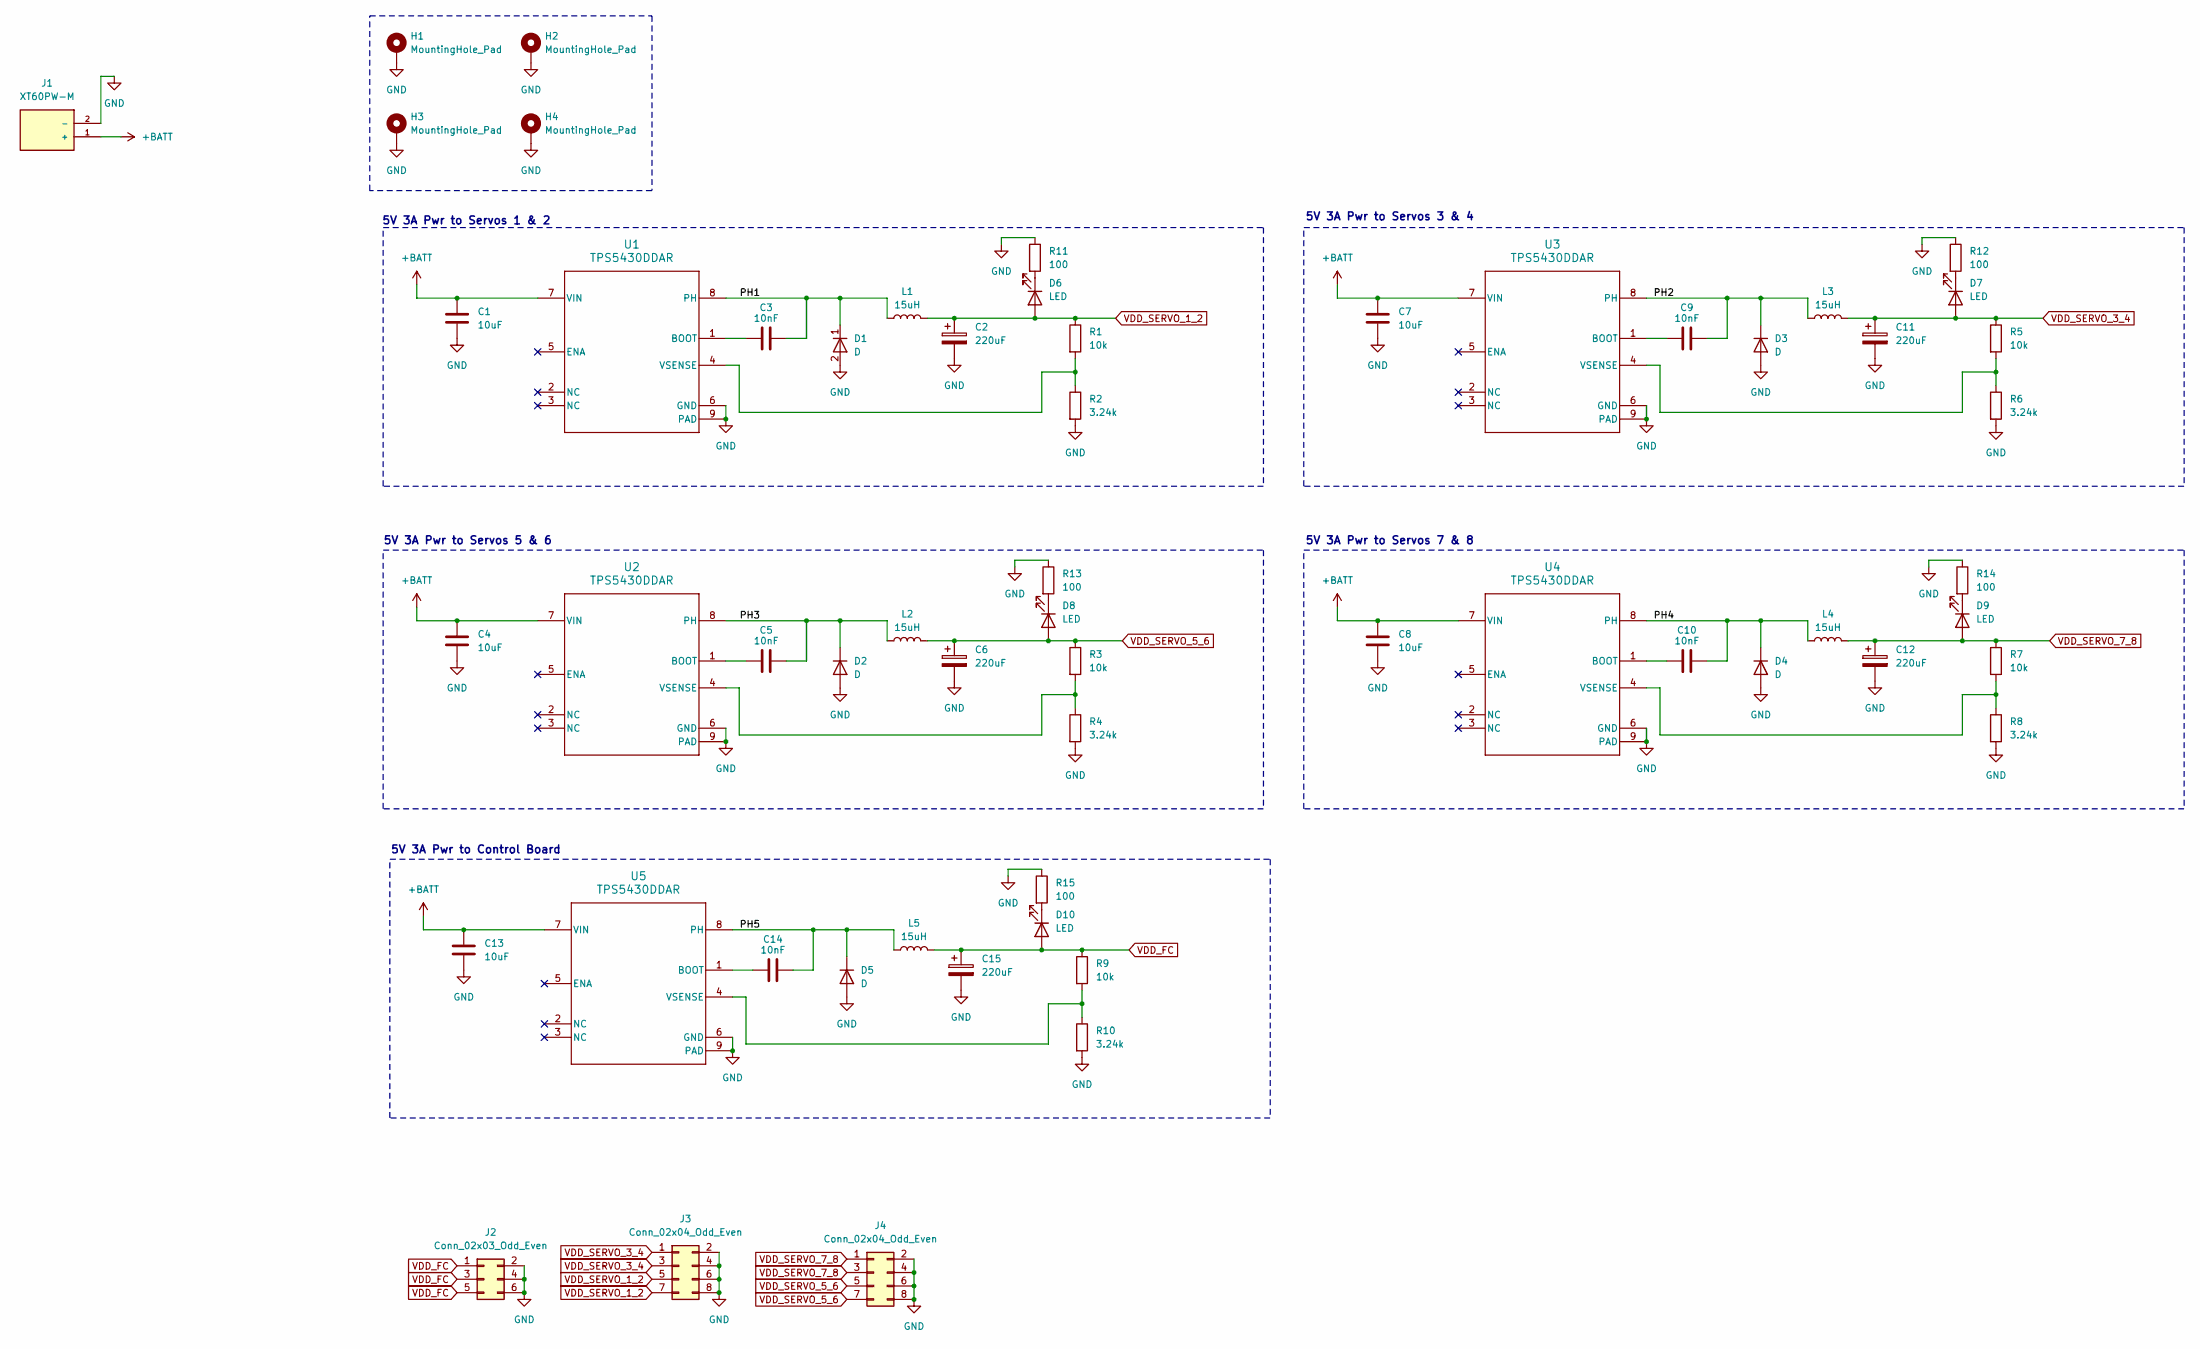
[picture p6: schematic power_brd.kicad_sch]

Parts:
C1, C4, C7, C8, C13: 10uF; C_1206_3216Metric_Pad1.33x1.80mm_HandSolder; LCSC Part # C13585
C2, C6, C11, C12, C15: 220uF; 10TPE220ML; LCSC Part # C147767
C3, C5, C9, C10, C14: 10nF; C_0805_2012Metric_Pad1.18x1.45mm_HandSolder; LCSC Part # C1710
D1, D2, D3, D4, D5: D; SMA_L4.3-W2.6-LS5.2-RD; LCSC Part # C8678
D6, D7, D8, D9, D10: LED; LED_0805_2012Metric_Pad1.15x1.40mm_HandSolder; LCSC Part # C84256
H1, H2, H3, H4: MountingHole_Pad; MountingHole_3.2mm_M3_Pad_Via
J1: XT60PW-M
J2: Conn_02x03_Odd_Even; PinHeader_2x03_P2.54mm_Vertical
J3, J4: Conn_02x04_Odd_Even; PinHeader_2x04_P2.54mm_Vertical
L1, L2, L3, L4, L5: 15uH; IND-SMD_L7.1-W6.6; LCSC Part # C22463824
R1, R3, R5, R7, R9: 10k; R_0805_2012Metric_Pad1.20x1.40mm_HandSolder; LCSC Part # C17414
R2, R4, R6, R8, R10: 3.24k; R_0805_2012Metric_Pad1.20x1.40mm_HandSolder; LCSC Part # C17609
R11, R12, R13, R14, R15: 100; R_0805_2012Metric_Pad1.20x1.40mm_HandSolder; LCSC Part # C17408
U1, U2, U3, U4, U5: TPS5430DDAR; LCSC Part # C9864

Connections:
+BATT: C1.1, C4.1, C7.1, C8.1, C13.1, J1.1 (+), U1.7 (VIN), U2.7 (VIN), U3.7 (VIN), U4.7 (VIN), U5.7 (VIN)
/PH1: C3.2, D1.1 (K), L1.1, U1.8 (PH)
/PH2: C9.2, D3.1 (K), L3.1, U3.8 (PH)
/PH3: C5.2, D2.1 (K), L2.1, U2.8 (PH)
/PH4: C10.2, D4.1 (K), L4.1, U4.8 (PH)
/PH5: C14.2, D5.1 (K), L5.1, U5.8 (PH)
GND: C1.2, C2.2, C4.2, C6.2, C7.2, C8.2, C11.2, C12.2, C13.2, C15.2, D1.2 (A), D2.2 (A), D3.2 (A), D4.2 (A), D5.2 (A), H1.1, H2.1, H3.1, H4.1, J1.2 (-), J2.2, J2.4, J2.6, J3.2, J3.4, J3.6, J3.8, J4.2, J4.4, J4.6, J4.8, R2.2, R4.2, R6.2, R8.2, R10.2, R11.1, R12.1, R13.1, R14.1, R15.1, U1.6 (GND), U1.9 (PAD), U2.6 (GND), U2.9 (PAD), U3.6 (GND), U3.9 (PAD), U4.6 (GND), U4.9 (PAD), U5.6 (GND), U5.9 (PAD)
unnamed: D6.1 (K), R11.2
unnamed: D7.1 (K), R12.2
unnamed: D8.1 (K), R13.2
unnamed: D9.1 (K), R14.2
unnamed: D10.1 (K), R15.2
unnamed: C3.1, U1.1 (BOOT)
unnamed: R1.2, R2.1, U1.4 (VSENSE)
unnamed: C5.1, U2.1 (BOOT)
unnamed: R3.2, R4.1, U2.4 (VSENSE)
unnamed: C9.1, U3.1 (BOOT)
unnamed: R5.2, R6.1, U3.4 (VSENSE)
unnamed: C10.1, U4.1 (BOOT)
unnamed: R7.2, R8.1, U4.4 (VSENSE)
unnamed: C14.1, U5.1 (BOOT)
unnamed: R9.2, R10.1, U5.4 (VSENSE)
VDD_FC: C15.1, D10.2 (A), J2.1, J2.3, J2.5, L5.2, R9.1
VDD_SERVO_1_2: C2.1, D6.2 (A), J3.5, J3.7, L1.2, R1.1
VDD_SERVO_3_4: C11.1, D7.2 (A), J3.1, J3.3, L3.2, R5.1
VDD_SERVO_5_6: C6.1, D8.2 (A), J4.5, J4.7, L2.2, R3.1
VDD_SERVO_7_8: C12.1, D9.2 (A), J4.1, J4.3, L4.2, R7.1

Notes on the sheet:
5V 3A Pwr to Servos 3 & 4
5V 3A Pwr to Servos 7 & 8
5V 3A Pwr to Servos 5 & 6
5V 3A Pwr to Servos 1 & 2
5V 3A Pwr to Control Board

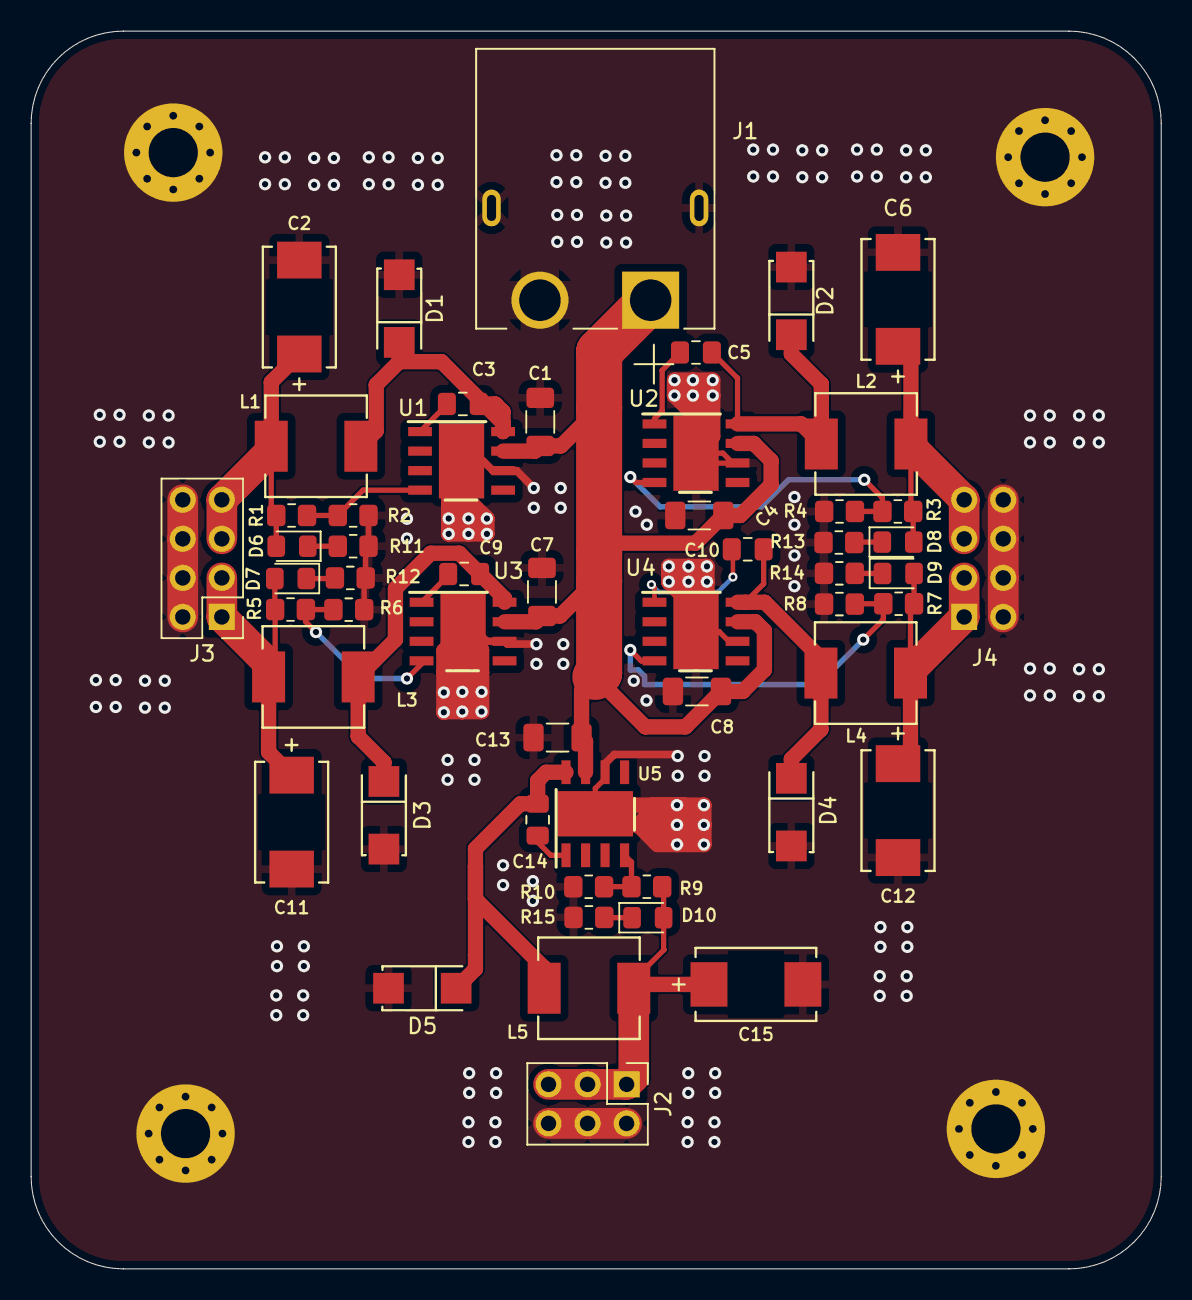
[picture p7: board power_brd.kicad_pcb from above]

Board: 4 copper layers, 73.5 x 80.5 mm, 58 parts (1 on the bottom side), 27 nets.

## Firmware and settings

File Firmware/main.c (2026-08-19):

#include <stdbool.h>
#include <stdio.h>
#include <string.h>

#include "hal.h"
#include "platform.h"
#include "target.h"

#include "core/core.h"

#include "FreeRTOS.h"
#include "task.h"

#include "drivers/bus/spi.h"
#include "drivers/serial/serial_link.h"
#include "drivers/serial/uart.h"

#include "tasks/imu/imu_task.h"
#include "tasks/mag/mag_task.h"
#include "tasks/baro/baro_task.h"
#include "tasks/gps/gps_task.h"
#include "tasks/rc/rc.h"
#include "tasks/nav/nav.h"
#include "tasks/guidance/guidance.h"
#include "tasks/control/control.h"
#include "tasks/mission/mission.h"
#include "tasks/shell/shell.h"
#include "tasks/serial_link/serial_link.h"
#include "tasks/sim/sim_telemetry.h"

/*
 * Stack-overflow trap (configCHECK_FOR_STACK_OVERFLOW == 2).
 *
 * By the time this runs the overflowing task has already scribbled past its
 * stack, so do NOT log from here - the logger is printf-shaped and wants the
 * very stack that just ran out. Park the task name somewhere a debugger can
 * read it and halt.
 */
char const* volatile g_pOverflowedTaskName = NULL;

void vApplicationStackOverflowHook (TaskHandle_t xTask, char* pcTaskName) {

    FJ_UNUSED (xTask);
    g_pOverflowedTaskName = pcTaskName;
    CriticalErrorHandler ();
}

FJ_DEFINE_SHARED (bool volatile, s_IsCM4Stuck)     = false;
FJ_DEFINE_SHARED (bool volatile, s_IsSystemInited) = false;
FJ_DEFINE_SHARED (bool volatile, s_IsCM4Ready)     = false;

/* ── FreeRTOS task resourcing ───────────────────────────────────────────────
 * main.c is the composition root: every task's XX_Task() lives in its own task
 * file; main() registers them per core below.
 */

#define TASK_PRIORITY_SENSOR_IMU 2U
#define TASK_PRIORITY_SENSOR_MAG 1U
/* Baro sits with mag at the bottom of the sensor group: it is a ~50 Hz part and
 * nothing consumes it on the flight path yet, so it must never preempt the
 * 400 Hz imu chain. */
#define TASK_PRIORITY_SENSOR_BARO 1U
/* GPS polls a UART-fed buffer at 100 Hz and nothing on the flight path consumes
 * it yet. One above baro/mag so a poll is not deferred behind them long enough
 * to miss a sentence - the driver only holds one. */
#define TASK_PRIORITY_SENSOR_GPS  2U
#define TASK_PRIORITY_SENSOR_RC  3U
#define TASK_PRIORITY_NAV        5U
#define TASK_PRIORITY_GUIDANCE   4U
#define TASK_PRIORITY_CONTROL    5U
#define TASK_PRIORITY_MISSION    3U

#define TASK_PRIORITY_SERIAL_RX 6U
#define TASK_PRIORITY_SIMTLM    1U
/*
 * The serial TX task sits at the lowest application priority deliberately. A
 * sustained log flood keeps it permanently runnable, and anywhere above 1 that
 * would starve mag and simtlm - the fault recorded as KnownIssues 2.6. At 1 it
 * time-slices with them instead, and the link degrades by dropping text.
 */
#define TASK_PRIORITY_SERIAL_TX 1U

/*
 * Stack depths are in WORDS (x4 for bytes) and are sized from measurement, not
 * guesswork: uxTaskGetStackHighWaterMark() was sampled for every task over a
 * SIL run. Peak usage observed, against the old allocation:
 *
 *     imu 99   mag 82   rc 82   mission 158   guidance 142
 *     control 253   nav 213   simrx 236   idle 24
 *
 * The mission figure is the smoking gun for the overflow that once wedged the
 * sim link with no diagnostic at all: 158 words used against 128 allocated. Its
 * locals are a umsg_rc_input_t (68 B) plus a umsg_nav_state_t (72 B) plus the
 * arming request and outgoing state - ~170 B of message structs before any call
 * frame - and it logs, which is printf-shaped and stack-hungry.
 *
 * Anything that can log is now given roughly 2x its measured peak, because a
 * log call is the largest and rarest frame each task takes. configCHECK_FOR_
 * STACK_OVERFLOW is on (see the hook above), so a regression halts loudly.
 */
#define STACK_SENSOR   256U   /* imu was at 77% of 128 - one LOG_ERROR from overflow.
                               * rc also carries the CRSF decode and its link
                               * up/down logging: measured 129 words peak, 50%. */
#define STACK_NAV      512U   /* 42% - fine */
#define STACK_GUIDANCE 384U
#define STACK_CONTROL  512U   /* 49% - fine */
#define STACK_MISSION  384U
/*
 * Measured over a SIL run with uxTaskGetStackHighWaterMark(), same method as
 * the table above: slrx peaked at 285 words, sltx at 51.
 *
 * sltx keeps 256 rather than being trimmed to its 51-word peak because that
 * measurement only covers the single-core path, where SyncProcessTasks() finds
 * an empty queue and returns immediately. In a dual-core build it runs the
 * logger's sink handler, and that path is deeper and unmeasured.
 */
#define STACK_SERIAL_RX       512U   /* 285 used - the shell decode and its logs land here now */
#define STACK_SERIAL_TX       256U   /* 51 used single-core; must never log (see serial_link.c) */
#define STACK_SIMTLM          256U

/*
 * Every task below is required for flight, so a failed creation must not be
 * allowed to pass quietly - the vehicle would boot into a scheduler missing,
 * say, the control loop. xTaskCreate only fails by returning
 * errCOULD_NOT_ALLOCATE_REQUIRED_MEMORY, i.e. the heap ran out.
 *
 * LOG_ERROR is safe here: the scheduler is not running yet, so SerialLink
 * bypasses its buffering and writes straight to the UART. At CFG_LOG_LEVEL
 * none the message compiles out, but the halt still happens.
 */
#define CREATE_TASK(fn, name, stack, prio)                                       \
    do {                                                                         \
        if (xTaskCreate ((fn), (name), (stack), NULL, (prio), NULL) != pdPASS) { \
            LOG_ERROR ("Failed to create task: %s", (name));                     \
            CriticalErrorHandler ();                                             \
        }                                                                        \
    } while (0)

int main (void) {

    if (Platform_Init () != 0) {
        CriticalErrorHandler ();
    }

#if defined(CORE_CM7)

    if (STATUS_FAIL (Spi_InitSystem ())) {
        CriticalErrorHandler ();
    }

    if (STATUS_FAIL (Uart_InitSystem ())) {
        CriticalErrorHandler ();
    }

    if (STATUS_FAIL (Core_Init ())) {
        CriticalErrorHandler ();
    }

    /* Sole owner of the debug UART. Log text and binary frames share it, so
     * logging and the shell stay available in a sim build. */
    if (STATUS_FAIL (SerialLink_Init ())) {
        CriticalErrorHandler ();
    }

#if !defined(SINGLE_CORE)
    s_IsSystemInited = true;
    while (!s_IsCM4Ready) {
        // allow cm4 to initialize logger
    };
#endif /* !SINGLE_CORE */

#ifdef SIM_HIL
    if (STATUS_FAIL (SimTelemetry_Init ())) {
        LOG_ERROR ("Failed to init sim telemetry");
        CriticalErrorHandler ();
    }
#endif

    if (STATUS_FAIL (Shell_Init ())) {
        LOG_ERROR ("Failed to init shell");
        CriticalErrorHandler ();
    }

    LOG_INFO ("Starting scheduler");
    CREATE_TASK (Imu_Task,          "imu",      STACK_SENSOR,    TASK_PRIORITY_SENSOR_IMU);
    CREATE_TASK (Mag_Task,          "mag",      STACK_SENSOR,    TASK_PRIORITY_SENSOR_MAG);
    CREATE_TASK (Baro_Task,         "baro",     STACK_SENSOR,    TASK_PRIORITY_SENSOR_BARO);
    CREATE_TASK (Gps_Task,          "gps",      STACK_SENSOR,    TASK_PRIORITY_SENSOR_GPS);
    CREATE_TASK (Rc_Task,           "rc",       STACK_SENSOR,    TASK_PRIORITY_SENSOR_RC);
    CREATE_TASK (Nav_Task,          "nav",      STACK_NAV,       TASK_PRIORITY_NAV);
    CREATE_TASK (Guidance_Task,     "guidance", STACK_GUIDANCE,  TASK_PRIORITY_GUIDANCE);
    CREATE_TASK (Control_Task,      "control",  STACK_CONTROL,   TASK_PRIORITY_CONTROL);
    CREATE_TASK (Mission_Task,      "mission",  STACK_MISSION,   TASK_PRIORITY_MISSION);
    CREATE_TASK (SerialLink_RxTask, "slrx",     STACK_SERIAL_RX, TASK_PRIORITY_SERIAL_RX);
    CREATE_TASK (SerialLink_TxTask, "sltx",     STACK_SERIAL_TX, TASK_PRIORITY_SERIAL_TX);
#ifdef SIM_HIL
    CREATE_TASK (SimTelemetry_Task, "simtlm",   STACK_SIMTLM,    TASK_PRIORITY_SIMTLM);
#endif

    LOG_INFO ("Heap Free Size: %u", (uint16_t)xPortGetFreeHeapSize ());
    vTaskStartScheduler ();
#endif /* CORE_CM7 */

/*
 * ******************* CM4 Start *******************
 */
#if defined(CORE_CM4)

    while (!s_IsSystemInited) {
        // wait for cm7 to init system
    };

    if (Core_Init () != eSTATUS_SUCCESS) {
        s_IsCM4Stuck = true;
        CriticalErrorHandler ();
    }

    s_IsCM4Ready = true;
    LOG_INFO ("Starting scheduler");
    /*
     * No application tasks. The receiver used to live here and reach CM7 through
     * shared memory; it is now part of Rc_Task on CM7, which removed the last
     * cross-core data flow. The scheduler still starts so the core has an idle
     * task and the logger's sync path keeps working.
     *
     * CM4 is idle capacity. Note that whatever lands here next cannot publish a
     * umsg topic to a CM7 subscriber - umsg is plain FreeRTOS queues with
     * per-core metadata, so it does not cross cores. Use core/sync.c for that.
     */
    vTaskStartScheduler ();

#endif /* CORE_CM4 */
    while (1);
}

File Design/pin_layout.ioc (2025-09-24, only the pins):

Mcu.UserName=STM32H747BITx
PA0.Signal=S_TIM5_CH1
PA1.Signal=S_TIM5_CH2
PA2.Signal=S_TIM5_CH3
PA3.Signal=S_TIM5_CH4
PA5.Signal=SPI1_SCK
PA6.Signal=SPI1_MISO
PA7.Signal=SPI1_MOSI
PB14.Signal=USART1_TX
PB15.Signal=USART1_RX
PB6.Signal=I2C1_SCL
PB7.Signal=I2C1_SDA
PC10.Signal=SPI3_SCK
PC11.Signal=SPI3_MISO
PC12.Signal=SPI3_MOSI
PC4.Signal=GPIO_Output
PC5.Signal=GPXTI5
PC6.Signal=S_TIM8_CH1
PC7.Signal=S_TIM8_CH2
PC8.Signal=S_TIM8_CH3
PC9.Signal=S_TIM8_CH4
PE2.Signal=GPIO_Output
PE3.Signal=GPIO_Output
PE4.Signal=GPIO_Output
PE5.Signal=GPIO_Output
PE6.Signal=GPIO_Output
PF0.Signal=I2C2_SDA
PF1.Signal=I2C2_SCL
PF10.Signal=GPIO_Output
PF3.Signal=GPXTI3
PF4.Signal=GPIO_Output
PF6.Signal=GPXTI6
PF7.Signal=SPI5_SCK
PF8.Signal=SPI5_MISO
PF9.Signal=SPI5_MOSI
PH6.Signal=S_TIM12_CH1
PH9.Signal=S_TIM12_CH2

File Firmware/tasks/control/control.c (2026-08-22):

#include "tasks/control/control.h"
#include "tasks/control/mixer.h"

#include "common/pid.h"

#include "devices/motors.h"
#include "devices/servos.h"

#include "umsg_guidance.h"
#include "umsg_mission.h"
#include "umsg_nav.h"
#include "umsg_tune.h"

#include "FreeRTOS.h"
#include "task.h"

#include <string.h>

/*
 * This loop paces ITSELF, rather than running once per guidance setpoint.
 *
 * Blocking on guidance made guidance's publish rate the control task's clock -
 * an undocumented coupling that put the actuator loop at the mercy of anything
 * upstream of it in the nav -> guidance chain. All three inputs are latest-value
 * reads now, so a stalled producer costs a stale input rather than a stopped
 * controller.
 *
 * xTaskDelayUntil rather than vTaskDelay: the latter delays for the period
 * AFTER the work, so the real rate is (work + delay) and drifts with load.
 *
 * The period is ticks-per-second divided by the rate, NOT pdMS_TO_TICKS of a
 * millisecond period. At 500 Hz on a 1000 Hz tick both spell 2 ms, but the
 * moment the rate stops being a whole number of milliseconds the pdMS_TO_TICKS
 * form truncates and silently runs fast. The assert keeps the two honest: if
 * either value changes so the rate no longer divides the tick exactly, this
 * fails to build rather than quietly running at something else.
 *
 * 500 Hz rather than 400 because configTICK_RATE_HZ is 1000 and 1000/400 is
 * 2.5 ticks, which cannot be expressed. The pair was 400 Hz on a 2000 Hz tick
 * until the tick was halved to cut the timer ISR load; the PID takes dt per
 * call and the PT1 filters are parameterised by cutoff rather than by a fixed
 * coefficient, so neither needed retuning for the new rate.
 */
#define CONTROL_RATE_HZ      500U
#define CONTROL_PERIOD_TICKS (configTICK_RATE_HZ / CONTROL_RATE_HZ)

_Static_assert ((configTICK_RATE_HZ % CONTROL_RATE_HZ) == 0U,
                "CONTROL_RATE_HZ must divide configTICK_RATE_HZ exactly");

// Plausible bounds on one control interval. dt is still MEASURED rather than
// assumed from the period above - an overrun should scale the integral and
// derivative by the time that actually passed, not by the time intended.
#define CONTROL_DT_MIN_S 0.0005f
#define CONTROL_DT_MAX_S 0.02f

typedef struct {
    umsg_sub_handle_t    guidance_sub;
    umsg_sub_handle_t    nav_sub;
    umsg_sub_handle_t    mission_sub;
    umsg_sub_handle_t    tune_sub;
    uint32_t             usLastUpdateTime;
    umsg_nav_state_t     nav;
    umsg_mission_state_t mission;
    umsg_guidance_setpoints_t sp;
} Control_t;

static Control_t s_Control;

#define PID_CREATE_AXIS(AXIS_NAME) \
    { .p = CFG_PID_##AXIS_NAME##_P, .i = CFG_PID_##AXIS_NAME##_I, .d = CFG_PID_##AXIS_NAME##_D, .integralLimit = CFG_PID_INTEGRAL_LIMIT }

static Pid_t     s_pid = { .axes = {
    [AXIS_IDX_ROLL] = PID_CREATE_AXIS (ROLL),
    [AXIS_IDX_PITCH] = PID_CREATE_AXIS (PITCH),
    [AXIS_IDX_YAW] = PID_CREATE_AXIS (YAW),
    [AXIS_IDX_THROTTLE] = PID_CREATE_AXIS (THROTTLE),
    }
};

static Motors_t s_motors    = { 0 };
static bool     s_prevArmed = false;
static bool     s_prevAltHold = false;

eSTATUS_t Control_Init(void) {
    
    s_Control.guidance_sub      = umsg_guidance_setpoints_subscribe(1, 1);
    s_Control.nav_sub           = umsg_nav_state_subscribe(1, 1);
    s_Control.mission_sub       = umsg_mission_state_subscribe(1, 1);
    s_Control.tune_sub          = umsg_tune_pid_subscribe(1, 1);
    s_Control.usLastUpdateTime  = GetMicroseconds();

    eSTATUS_t status = eSTATUS_SUCCESS;
    do {
        if (STATUS_FAIL (Motors_Init (&s_motors))) {
            LOG_ERROR ("Failed to initialize Motors");
            status = eSTATUS_FAILURE;
            break;
        }

        if (STATUS_FAIL (Servos_Init ())) {
            LOG_ERROR ("Failed to initialize Servos");
            status = eSTATUS_FAILURE;
            break;
        }
        if (STATUS_FAIL (Mixer_Init ())) {
            LOG_ERROR ("Failed to initialize mixer");
            status = eSTATUS_FAILURE;
            break;
        }
        if (STATUS_FAIL (Pid_Init (&s_pid))) {
            LOG_ERROR ("Failed to initialize pid");
            status = eSTATUS_FAILURE;
            break;
        }
    } while(0);

    return status;
}

eSTATUS_t Control_Update(void) {

    /* Latest-value caches, all three: the queues are length 1 (overwrite) and
     * receive() consumes, so keep the last value for iterations with no new
     * message. The setpoint is now cached like the other two - this loop runs
     * on its own clock and must not stall waiting for one. */
    umsg_guidance_setpoints_receive(s_Control.guidance_sub, &s_Control.sp, 0);
    umsg_nav_state_receive(s_Control.nav_sub, &s_Control.nav, 0);
    umsg_mission_state_receive(s_Control.mission_sub, &s_Control.mission, 0);

    bool armed = s_Control.mission.armed != 0;
    if (armed && !s_motors.armed) {
        /*
         * Called every iteration, not on the arm edge: the ESC arms only after a
         * continuous run of zero-throttle frames, and Dshot_Arm emits exactly one
         * per call. This loop is the frame clock, which puts them CONTROL_RATE_HZ
         * apart - 2 ms, inside the 5 ms an ESC tolerates - and keeps the handshake
         * off the CPU. It used to block here for 350 ms.
         *
         * s_motors.armed rather than the s_prevArmed edge, because the condition
         * has to stay true for the whole handshake rather than for one iteration.
         */
        Motors_Arm(&s_motors);
    } else if (!armed && s_prevArmed) {
        Motors_Disarm(&s_motors);
    }
    s_prevArmed = armed;

    umsg_tune_pid_t tune;
    if (umsg_tune_pid_receive(s_Control.tune_sub, &tune, 0) && tune.axis < AXIS_IDX_COUNT) {
        PidAxis_t* pAxis = &s_pid.axes[tune.axis];
        switch (tune.gain) {
            case TUNE_PID_GAIN_KP:             pAxis->p = tune.value; break;
            case TUNE_PID_GAIN_KI:             pAxis->i = tune.value; break;
            case TUNE_PID_GAIN_KD:             pAxis->d = tune.value; break;
            case TUNE_PID_GAIN_INTEGRAL_LIMIT: pAxis->integralLimit = tune.value; break;
            default: break;
        }
    }

    uint32_t usNow = GetMicroseconds();
    float dt = (float)(usNow - s_Control.usLastUpdateTime) / 1000000.0f;
    s_Control.usLastUpdateTime = usNow;

    // The loop is paced by queued IMU samples, so a drained burst can put two
    // iterations in the same microsecond (dt == 0) and a stall can produce an
    // arbitrarily long one. Neither is a real control interval; bound dt rather
    // than let it scale the integral and derivative terms.
    dt = clipf32(dt, CONTROL_DT_MIN_S, CONTROL_DT_MAX_S);
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

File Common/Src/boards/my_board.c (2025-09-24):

#include "conf/boards/my_board.h"
#include "conf/board.h"
#include "conf/ids.h"
#include "hal.h"

static TimerBoardConf_t gTimerBoardConfs[] = {

    { TIMER_ID_MAKE (eTIMER_5_DEV_ID, eTIMER_CHANNEL_1_ID),
      GPIO_ID_MAKE (eGPIO_PORTID_A, eGPIO_PINID_0) },
    { TIMER_ID_MAKE (eTIMER_5_DEV_ID, eTIMER_CHANNEL_2_ID),
      GPIO_ID_MAKE (eGPIO_PORTID_A, eGPIO_PINID_1) },
    { TIMER_ID_MAKE (eTIMER_5_DEV_ID, eTIMER_CHANNEL_3_ID),
      GPIO_ID_MAKE (eGPIO_PORTID_A, eGPIO_PINID_2) },
    { TIMER_ID_MAKE (eTIMER_5_DEV_ID, eTIMER_CHANNEL_4_ID),
      GPIO_ID_MAKE (eGPIO_PORTID_A, eGPIO_PINID_3) },

    { TIMER_ID_MAKE (eTIMER_8_DEV_ID, eTIMER_CHANNEL_1_ID),
      GPIO_ID_MAKE (eGPIO_PORTID_C, eGPIO_PINID_6) },
    { TIMER_ID_MAKE (eTIMER_8_DEV_ID, eTIMER_CHANNEL_2_ID),
      GPIO_ID_MAKE (eGPIO_PORTID_C, eGPIO_PINID_7) },
    { TIMER_ID_MAKE (eTIMER_8_DEV_ID, eTIMER_CHANNEL_3_ID),
      GPIO_ID_MAKE (eGPIO_PORTID_C, eGPIO_PINID_8) },
    { TIMER_ID_MAKE (eTIMER_8_DEV_ID, eTIMER_CHANNEL_4_ID),
      GPIO_ID_MAKE (eGPIO_PORTID_C, eGPIO_PINID_9) },

    { TIMER_ID_MAKE (eTIMER_12_DEV_ID, eTIMER_CHANNEL_1_ID),
      GPIO_ID_MAKE (eGPIO_PORTID_H, eGPIO_PINID_6) },
    { TIMER_ID_MAKE (eTIMER_12_DEV_ID, eTIMER_CHANNEL_2_ID),
      GPIO_ID_MAKE (eGPIO_PORTID_H, eGPIO_PINID_9) },
};

#define TIM5_CH1_IDX  0
#define TIM5_CH2_IDX  1
#define TIM5_CH3_IDX  2
#define TIM5_CH4_IDX  3
#define TIM8_CH1_IDX  4
#define TIM8_CH2_IDX  5
#define TIM8_CH3_IDX  6
#define TIM8_CH4_IDX  7
#define TIM12_CH1_IDX 8
#define TIM12_CH2_IDX 9

static SPIBoardConf_t gSPIBoardConfs[] = {

    {
    { eSPI_1_BUS_ID },
    GPIO_ID_MAKE (eGPIO_PORTID_A, eGPIO_PINID_5),
    GPIO_ID_MAKE (eGPIO_PORTID_A, eGPIO_PINID_6),
    GPIO_ID_MAKE (eGPIO_PORTID_A, eGPIO_PINID_7),
    1000U, // 1 MHz
    GPIO_AF5_SPI1,
    },

    {
    { eSPI_3_BUS_ID },
    GPIO_ID_MAKE (eGPIO_PORTID_C, eGPIO_PINID_10),
    GPIO_ID_MAKE (eGPIO_PORTID_C, eGPIO_PINID_11),
    GPIO_ID_MAKE (eGPIO_PORTID_C, eGPIO_PINID_12),
    1000U, // 1 MHz
    GPIO_AF5_SPI3,
    },
    {
    { eSPI_5_BUS_ID },
    GPIO_ID_MAKE (eGPIO_PORTID_F, eGPIO_PINID_7),
    GPIO_ID_MAKE (eGPIO_PORTID_F, eGPIO_PINID_8),
    GPIO_ID_MAKE (eGPIO_PORTID_F, eGPIO_PINID_9),
    1000U, // 1 MHz
    GPIO_AF5_SPI5,
    }
};

#define SPI1_IDX 0
#define SPI3_IDX 1
#define SPI5_IDX 2

static UARTBoardConf_t gUARTBoardConfs[] = {

    { { eUART_1_BUS_ID },
      GPIO_ID_MAKE (eGPIO_PORTID_B, eGPIO_PINID_14),
      GPIO_ID_MAKE (eGPIO_PORTID_B, eGPIO_PINID_15) },

    { { eUART_2_BUS_ID },
      GPIO_ID_MAKE (eGPIO_PORTID_D, eGPIO_PINID_5),
      GPIO_ID_MAKE (eGPIO_PORTID_D, eGPIO_PINID_6) },

    { { eUART_3_BUS_ID },
      GPIO_ID_MAKE (eGPIO_PORTID_B, eGPIO_PINID_10),
      GPIO_ID_MAKE (eGPIO_PORTID_B, eGPIO_PINID_11) }
};

#define UART1_IDX 0
#define UART2_IDX 1
#define UART3_IDX 2

static I2CBoardConf_t gI2CBoardConfs[] = {

    { { eI2C_1_BUS_ID },
      GPIO_ID_MAKE (eGPIO_PORTID_B, eGPIO_PINID_6),
      GPIO_ID_MAKE (eGPIO_PORTID_B, eGPIO_PINID_7) }
};

#define I2C1_IDX 0

static DeviceBoardConf_t gDeviceBoardConfs[] = {

    { eIMU_DEVICE_ID,
      { eEXTI_5_ID, GPIO_ID_MAKE (eGPIO_PORTID_C, eGPIO_PINID_5) },
      (BusHeaderBoardConf_t*)&gSPIBoardConfs[SPI1_IDX],
      GPIO_ID_MAKE (eGPIO_PORTID_C, eGPIO_PINID_4) },

    { eMAG_DEVICE_ID,
      { eEXTI_3_ID, GPIO_ID_MAKE (eGPIO_PORTID_F, eGPIO_PINID_3) },
      (BusHeaderBoardConf_t*)&gSPIBoardConfs[SPI5_IDX],
      GPIO_ID_MAKE (eGPIO_PORTID_F, eGPIO_PINID_4) },

    { eBARO_DEVICE_ID,
      { eEXTI_4_ID, GPIO_ID_MAKE (eGPIO_PORTID_F, eGPIO_PINID_10) },
      (BusHeaderBoardConf_t*)&gSPIBoardConfs[SPI5_IDX],
      GPIO_ID_MAKE (eGPIO_PORTID_F, eGPIO_PINID_6) },

    { eFLASH_DEVICE_ID,
      { eEXTI_ID_NULL, eGPIO_ID_NULL },
      (BusHeaderBoardConf_t*)&gSPIBoardConfs[SPI3_IDX],
      GPIO_ID_MAKE (eGPIO_PORTID_F, eGPIO_PINID_10) },

    { eSERIAL_DEBUG_DEVICE_ID,
      { eEXTI_ID_NULL, eGPIO_ID_NULL },
      (BusHeaderBoardConf_t*)&gUARTBoardConfs[UART1_IDX],
      GPIO_ID_MAKE (eGPIO_PORTID_F, eGPIO_PINID_1) },

    { eGPS_DEVICE_ID,
      { eEXTI_ID_NULL, eGPIO_ID_NULL },
      (BusHeaderBoardConf_t*)&gUARTBoardConfs[UART2_IDX],
      eGPIO_ID_NULL },

    { eRF_RECEIVER_DEVICE_ID,
      { eEXTI_ID_NULL, eGPIO_ID_NULL },
      (BusHeaderBoardConf_t*)&gUARTBoardConfs[UART3_IDX],
      eGPIO_ID_NULL },

    { eCURRENT_SENSOR_DEVICE_ID,
      { eEXTI_ID_NULL, eGPIO_ID_NULL },
      (BusHeaderBoardConf_t*)&gI2CBoardConfs[I2C1_IDX],
      eGPIO_ID_NULL }
};
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

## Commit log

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2025-04-05 fixed dual core debug config
    [main.c]
2025-04-06 fixed bug with uart on cm4
    [main.c, sync.c]
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2025-06-14 added imu soft reset for bmi323
    [imu.c, main.c]
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2025-06-17 fixed hard coded status values
    [main.c]
2025-06-19 added better error reporting for IMU
    [imu.c, main.c]
2025-06-21 reduced spi2 baudrate and got correct chip id from imu
    [main.c]
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2025-06-28 fixed imu read register bug
    [imu.c, main.c]
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2025-06-28 fixed narrowing data type bug in IMUGetConf
    [imu.c, main.c]
2025-06-29 fixed bug with sign extension are imu gyro and accel data
    [imu.c]
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2025-07-03 rework pwm, servos and motors
    [imu.c, main.c]
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2025-07-06 fixed error with dt not being converted to seconds
    [imu.c, main.c]
2025-07-06 added function to warmup madgwick filter on startup and the gui now creates seperate sessions for each serial connect and disconnect
2025-07-06 fixed bug in IMUPollData where while loop would always hit timeout
    [imu.c, main.c]
2025-07-07 fixed bug with uart overwritting logs
    [main.c, sync.c]
2025-07-07 partial fix to filter.c and imu.c tests
2025-07-08 fixed bug in queue where index wrapping was incorrect
    [sync.c]
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2025-07-10 fixed failing imu tests
    [imu.c]
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2025-07-17 fixed dma ptr error
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2025-07-27 fixed dshot timing issues
    [imu.c, main.c]
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2025-07-31 fixed bug in IMUProcessUpdatefromINT
    [imu.c]
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2025-08-06 fixed flag in control.c
    [control.c, main.c]
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2025-08-11 fixed imu tests and bug in imucalibrate
    [imu.c, main.c]
2025-08-19 design files
    [fc.kicad_pcb, fc.kicad_sch]
2025-08-19 finished power layout for fc
    [fc.kicad_sch, flight_controller.kicad_sch, power.kicad_sch]
2025-08-20 started on swd interface
    [flight_controller.kicad_sch]
2025-08-20 crlf vs lf for kicad
    [flight_controller.kicad_sch]
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2025-08-20 added debug connector
    [flight_controller.kicad_sch]
2025-08-21 started adding periphs
    [flight_controller.kicad_sch]
2025-08-22 continuing to add periphs
    [flight_controller.kicad_sch]
2025-08-22 added pull up resistors
    [flight_controller.kicad_sch]
2025-08-25 refactored pins
    [flight_controller.kicad_sch]
2025-08-26 add rf receiver connector
    [flight_controller.kicad_sch]
2025-08-27 added flash memory
    [flight_controller.kicad_sch, power.kicad_sch]
2025-08-28 started adding footprints and filling out bom
    [flight_controller.kicad_sch, power.kicad_sch]
2025-08-29 started layout
    [fc.kicad_pcb, flight_controller.kicad_sch, power.kicad_sch]
2025-08-29 started laying out voltage regulator
    [fc.kicad_pcb, flight_controller.kicad_sch, power.kicad_sch]
2025-08-31 before shrinking pcb
    [fc.kicad_pcb, flight_controller.kicad_sch, power.kicad_sch]
2025-09-01 finished pcb layout and started on bom
    [fc.kicad_pcb, flight_controller.kicad_sch, power.kicad_sch]
2025-09-02 finished filling out bom
    [fc.kicad_pcb, flight_controller.kicad_sch, power.kicad_sch]
2025-09-03 edited servo connector layout to support larger connectors
    [fc.kicad_pcb]
2025-09-04 extended smd pads for lga packages
    [fc.kicad_pcb, flight_controller.kicad_sch]
2025-09-04 updated silkscreen
    [fc.kicad_pcb]
2025-09-09 modified bom for serial connector
    [flight_controller.kicad_sch]
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2025-09-30 added a bus interface to handle setting up and various busses for devices
2025-10-06 added fabrication plugin to kicad
    [bom.csv, designators.csv]
2025-10-08 started v2
    [fc.kicad_pcb, fc.kicad_sch, flight_controller.kicad_sch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]
2025-10-08 added servo and control board power
    [power_brd.kicad_pcb, power_brd.kicad_sch]
2025-10-09 started on power pcb
    [power_brd.kicad_pcb, power_brd.kicad_sch]
2025-10-09 laying out power board
    [power_brd.kicad_pcb, power_brd.kicad_sch]
2025-10-11 mostly finished power board layout
    [power_brd.kicad_pcb, power_brd.kicad_sch]
2025-10-14 power board
    [fc.kicad_pcb, flight_controller.kicad_sch, power.kicad_sch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]
2025-10-15 editing bom
    [flight_controller.kicad_sch, power.kicad_sch]
2025-10-15 added test pads for gps rf and debug
    [fc.kicad_pcb, flight_controller.kicad_sch]
2025-10-16 added symlink to Lib folder
    [bom.csv, designators.csv, fc.kicad_pcb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]
2025-10-16 added flash device
    [flight_controller.kicad_sch]
2025-10-17 layout changed to main fc board
    [fc.kicad_pcb, flight_controller.kicad_sch, power.kicad_sch]
2025-10-20 completed main fc board layout
    [fc.kicad_pcb, flight_controller.kicad_sch, power.kicad_sch]
2025-10-20 fc and power board sent out for assembly
    [fc.kicad_pcb, power_brd.kicad_pcb, power_brd.kicad_sch]
2025-10-26 fixed bug in ringbuffer init, shared_mem section is now zeroed before jmping to main, and fixed return value in imu update from polling function
    [control.c, flash.c, gps.c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]
2025-10-31 fixed bug with ringbuff size being initialized incorrectly
    [imu.c, mag.c, sync.c]
2025-11-01 fixed imu configuration bug
    [imu.c, main.c]
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2025-11-16 VCORE is regulated with LDO instead of SMPS. Remove VCAP connection to 3.3V as VCAP is an output not an input
    [fc.kicad_pcb, flight_controller.kicad_sch, power.kicad_sch]
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2026-02-05 removed freertos, the separate main.c for each core, and each core now uses its systick timer now that freertos is gone
2026-02-05 removed stm32cubeide settings files and update .vscode/c_cpp_properties.json file with new compiler path and the new include paths
2026-02-05 VCore regulator (SMPS or LDO) is now chosen via a macro defined by the board config
2026-02-06 added openocd through msys2, added openocd stm32h7 dual core config, add two configurations for Cortex-Debug extension to build the firmware, openocb connection, flash the firmware and attach gdb
    [stm32h747_dual_core.cfg]
2026-02-06 fixed clang-format bug in settings.json for setting the clang-format exe path
    [main.c]
2026-02-07 add svd files for both cores. Can now connect to the nucleo board using openocd and flash firmware. Fixed systemclock config
    [main.c]
2026-02-07 simplified spi and imu interface to a config header file. fw_build.py now outputs the cmake configure and build steps to their respective files in the build folder
2026-02-08 added dshot implementation that uses timer pwm channels to send dshot bits without using dma
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2026-02-09 Changed motor and servo api to handle all servos and motors. Now the mixer api is used to coordinate between the two groups
2026-02-09 removed old uart implementation. removed most of the board conf device interface
2026-02-10 removed mc.h and mc.c. The pid and filter initialization now happens in the main function before the scheduler is called
2026-02-11 added simple remote control interface and added a receiver callback to the uart port
2026-02-12 cleaned up most of the compiler warnings. removed bus and old spi implementation
2026-02-13 reworked pid interface
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2026-02-13 removed old pcb design file. ringbuffer no longer sets the given buffer to 0 during initialization
    [core_shared.h, imu.c]
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2026-02-22 changed filter api to no longer use a global filter struct
    [main.c]
2026-02-22 fixed bug with spi dummy bytes being accounted for incorrectly when reading from the imu
    [imu.c]
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2026-03-08 fixed usart1 setup where the incorrect AF id was being used. scale down by 2 APB1 and APB2 clocks if HSI (64MHz) is being used as the clock source to HCLK instead of HSE
    [core_shared.h, gpio.h, main.c]
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2026-05-18 added connect_assert_srst to openocd.cfg to force connecting under reset
    [stm32h747_dual_core.cfg]
2026-05-22 fixed dshot hil tests
    [main.c]
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2026-08-15 combined board.py, gui.py, and bridge.py
    [drone_motor.xml, plane.stl]
2026-08-15 setup renode to emulate the cm7 core and it talks to a jbsim for sil
    [drone_motor.xml]
2026-08-16 fixed servo duty cycle wrapping
    [core_shared.c]
2026-08-16 fixed dt bugged in pid and updated mission to only allow arming after attitude estimate has settled.
    [control.c, main.c]
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2026-08-19 introduced noise to some of the sensor data sent to the FC when running in the SIL
    [core_shared.c]
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2026-08-19 reworked mag driver to match other drivers
    [mag.c]
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2026-08-22 fixed bug where altitude would oscillate and sharp changes in roll and pitch would cause a crash
    [control.c]
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2026-08-22 added emulator for bmi323 to renode and removed imu sim driver as it is no longer needed
    [control.c, core_shared.c, core_shared.h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]
2026-08-22 motor arming now no longer blocks and relies on Control_Task to call arm until arming is complete
    [control.c, motors.c]
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2026-08-24 fixed roll and pitch overcommitting
    [sim_link.c]
